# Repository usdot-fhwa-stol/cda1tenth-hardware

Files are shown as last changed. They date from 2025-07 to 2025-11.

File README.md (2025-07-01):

# cda1tenth-hardware
This repository will host any files related to the hardware development of the CDA 1Tenth system for small-scale vehicles and infrastructure in the C-ADS context.

## Contribution
Welcome to the CARMA contributing guide. Please read this guide to learn about our development process, how to propose pull requests and improvements, and how to build and test your changes to this project. [CARMA Contributing Guide](https://github.com/usdot-fhwa-stol/carma-platform/blob/develop/Contributing.md) 

## Code of Conduct 
Please read our [CARMA Code of Conduct](https://github.com/usdot-fhwa-stol/carma-platform/blob/develop/Code_of_Conduct.md) which outlines our expectations for participants within the CARMA community, as well as steps to reporting unacceptable behavior. We are committed to providing a welcoming and inspiring community for all and expect our code of conduct to be honored. Anyone who violates this code of conduct may be banned from the community.

## Attribution
The development team would like to acknowledge the people who have made direct contributions to the design and code in this repository. [CARMA Attribution](https://github.com/usdot-fhwa-stol/carma-platform/blob/develop/ATTRIBUTION.txt) 

## License
By contributing to the Federal Highway Administration (FHWA) Connected Automated Research Mobility Applications (CARMA), you agree that your contributions will be licensed under its Apache License 2.0 license. [CARMA License](https://github.com/usdot-fhwa-stol/carma-platform/blob/develop/docs/License.md) 

## Contact
Please click on the CARMA logo below to visit the Federal Highway Adminstration(FHWA) CARMA website.

CARMA Image (https://highways.dot.gov/research/research-programs/operations/CARMA)

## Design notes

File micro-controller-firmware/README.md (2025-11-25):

# Micro-controller Firmware

This firmware runs on an ESP32-S3 microcontroller to control a 1/10th scale autonomous vehicle. It provides motor control, steering, IMU sensing, and ROS 2 integration via micro-ROS.

## Hardware Requirements

### Required Components

- **ESP32-S3-DevKitC-1** development board or [CDA1Tenth PCB](docs/10th_Scale_Board.drawio.png)
- **TMC5160 Stepper Drivers** (3x):
  - One for steering motor
  - One for left drive motor
  - One for right drive motor
- **LSM6DSO IMU** sensor (6-DOF accelerometer/gyroscope)
- **Motors**: Stepper motors for drive and steering
- **Power Supply**: Appropriate voltage/current for motors and ESP32
- **USB-C Cable**: For programming and micro-ROS communication

### Pin Connections

The firmware uses the following GPIO pins on the ESP32-S3:

| Pin | Function | Description |
| --- | --- | --- |
| **SPI Bus** | | |
| IO 11 | MOSI | SPI Master Out Slave In |
| IO 12 | SCK | SPI Clock |
| IO 13 | MISO | SPI Master In Slave Out |
| **Chip Select Pins** | | |
| IO 14 | CS_IMU | Chip select for LSM6DSO IMU |
| IO 39 | CS_RIGHT | Chip select for right motor TMC5160 (TMC 5160 (0)) |
| IO 40 | CS_LEFT | Chip select for left motor TMC5160 (TMC 5160 (1)) |
| IO 41 | CS_STEER | Chip select for steering motor TMC5160 (TMC 5160 (2)) |
| **Control Pins** | | |
| IO 4 | EN_PIN | Motor enable pin |
| IO 18 | STEERING_SENSOR | Steering angle sensor (analog input) |
| IO 37 | LED_PIN | Status LED |
| **Other Pins** | | |
| IO 0 | BOOT | Boot mode selection (normally floating, can be pulled low with S2) |
| EN | RESET | Reset pin (normally pulled up, can be pulled low with S1) |
| IO 1-2 | ESTOP | Emergency stop pins (connected to TMC5160 estop) |
| IO 17 | BATTERY_VOLTAGE | Battery voltage monitoring (1:8 voltage divider) |
| IO 19-20 | USB | USB connection pins |

> **Note:** A detailed PCB diagram (`10th_Scale_Board.drawio.png`) is available in the `docs/` folder showing the complete board layout, pin connections, and component placement.

## Building and Running

0. Install Platform IO using the following installation [guide](https://docs.platformio.org/en/latest/integration/ide/vscode.html#installation)

1. Build the project:

   ```bash
   pio run
   ```

2. Use a USB cable to connect your laptop to the micro-controller board's USB-C port

3. Put the ESP32 into the manual bootloader mode ([docs by EXPRESSIF](https://docs.espressif.com/projects/esptool/en/latest/esp32/advanced-topics/boot-mode-selection.html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)).

4. Upload to your ESP32:

   ```bash
   pio run --target upload
   ```

5. Monitor serial output:

   ```bash
   pio device monitor
   ```

## micro-ROS Agent Setup

The firmware communicates with ROS 2 through a micro-ROS agent that must be running on your computer. The agent bridges the serial connection between the ESP32 and your ROS 2 network.

### Quick Start

A startup script is provided (`micro-ros-startup.sh`) that launches the agent with the correct settings:

```bash
./micro-ros-startup.sh
```

### Manual Setup

If you need to run the agent manually or on a different system:

1. **Install micro-ROS Agent** (if using Vulcanexus distribution):

   ```bash
   source /opt/vulcanexus/humble/setup.bash
   ```

2. **Identify the serial port**:

   - **Linux**: Usually `/dev/ttyACM0` or `/dev/ttyUSB0`
   - **Windows**: Usually `COM3`, `COM4`, etc. (check Device Manager)
   - **macOS**: Usually `/dev/cu.usbmodem*` or `/dev/tty.usbmodem*`

3. **Run the agent**:

   ```bash
   ros2 run micro_ros_agent micro_ros_agent serial --dev <PORT> --baudrate 921600 -v6
   ```

   Example for Linux:

   ```bash
   ros2 run micro_ros_agent micro_ros_agent serial --dev /dev/ttyACM0 --baudrate 921600 -v6
   ```

   Example for Windows (using WSL or native):

   ```bash
   ros2 run micro_ros_agent micro_ros_agent serial --dev COM3 --baudrate 921600 -v6
   ```

### Verifying Connection

Once the agent is running and the ESP32 is powered on:

- The ESP32 LED should turn **ON** (solid) when connected
- You should see connection messages in the agent terminal
- You can verify topics are available:
  ```bash
  ros2 topic list
  ```
  You should see `/car/car_state` and `/car/debug_data` topics.

## ROS 2 Topics and Messages

The `car_controller` node communicates via the following ROS 2 topics:

### Subscriptions

| Topic | Message Type | Description | Rate |
| --- | --- | --- | --- |
| `/cmd_vel_filtered` | `geometry_msgs/Twist` | Velocity commands (linear.x, angular.z) | Variable |
| `/car/config` | `car_config_msg/CarConfig` | Configuration parameters | 1 Hz (from car_odometry node) |

**`/cmd_vel_filtered` (geometry_msgs/Twist):**

- `linear.x`: Forward/backward velocity in m/s
- `angular.z`: Rotational velocity in rad/s
- **Safety**: Commands timeout after 200ms if no new command is received (car stops)

**`/car/config` (car_config_msg/CarConfig):**

- `wheelbase`: Distance between front and rear axles (meters)
- `track_width`: Distance between left and right wheels (meters)
- `wheel_radius`: Wheel radius (meters)
- `encoder_offset`: Steering encoder offset (degrees)
- `max_steering_angle`: Maximum steering angle (degrees)
- `max_rpm`: Maximum motor RPM

### Publications

| Topic | Message Type | Description | Rate  |
| --- | --- | --- | ----- |
| `/car/car_state`  | `car_state_msg/CarState` | Complete car state (IMU, motors, steering) | 20 Hz |
| `/car/debug_data` | `std_msgs/Float32MultiArray` | Debug information array | 2 Hz  |

**`/car/car_state` (car_state_msg/CarState):**

- `header`: ROS 2 header with timestamp and frame_id ("base_link")
- `accel_x/y/z`: Accelerometer data (m/s²)
- `gyro_x/y/z`: Gyroscope data (rad/s)
- `speed`: Current car speed (m/s)
- `steering_angle`: Actual steering angle (degrees)
- `right_motor_rpm`: Right motor RPM
- `left_motor_rpm`: Left motor RPM

**`/car/debug_data` (std_msgs/Float32MultiArray):**

- Array of 20 float values containing debug information (see Debug Data section below)

### Viewing Topics

To monitor the car state:

```bash
ros2 topic echo /car/car_state
```

To send velocity commands:

```bash
ros2 topic pub --once /cmd_vel_filtered geometry_msgs/msg/Twist "{linear: {x: 0.5, y: 0.0, z: 0.0}, angular: {x: 0.0, y: 0.0, z: 0.2}}"
```

## System Architecture

The firmware implements a multi-timer control system with ROS 2 integration via micro-ROS:

```mermaid
graph TB

subgraph ROS["ROS 2 System"]
    CMD[cmd_vel_filtered]
    CONFIG[car/config]
    STATE[car_state]
    DEBUG[debug_data]
end

subgraph AGENT["micro-ROS Agent"]
    BRIDGE[Serial/USB Bridge]
end

subgraph FW["ESP32-S3 Firmware"]
    NODE[car_controller Node]
    CONTROL[Control Logic]
    SENSORS[Sensing]
    MOTORCTRL[Motor Control]
end

subgraph HW["Hardware"]
    MOTORS[Drive & Steering Motors]
    IMU[IMU]
    ENC[Steering Encoder]
    LED[Status LED]
end

%% ROS2 topics to micro-ROS Agent
CMD --> BRIDGE
CONFIG --> BRIDGE

%% Agent to Firmware
BRIDGE --> NODE

%% Main data flow inside firmware
NODE --> CONTROL
NODE --> SENSORS

SENSORS --> CONTROL
CONTROL --> MOTORCTRL

%% Firmware to hardware
MOTORCTRL --> MOTORS
SENSORS --> IMU
SENSORS --> ENC
CONTROL --> LED

%% Firmware publishes back to ROS 2
CONTROL --> STATE
CONTROL --> DEBUG
STATE --> BRIDGE
DEBUG --> BRIDGE
```

### Control Loops

1. **Control Timer** (20ms / 50 Hz)

   - Processes velocity commands
   - Calculates steering angles and motor speeds
   - Updates motor control loops
   - Updates IMU sensor readings

2. **Kinematics Timer** (50ms / 20 Hz)

   - Publishes car state to `/car/car_state`
   - Includes IMU data, motor RPMs, steering angle

3. **Debug Timer** (500ms / 2 Hz)
   - Publishes debug data array to `/car/debug_data`
   - Includes system health, timing, and diagnostic information

### Data Flow

The diagram above shows the complete system architecture. Key data flows:

- **Command Flow**: `/cmd_vel_filtered` → micro-ROS Agent → ESP32 → Motor Control
- **Configuration Flow**: `/car/config` → micro-ROS Agent → ESP32 → Parameter Updates
- **State Flow**: ESP32 Sensors → Control System → `/car/car_state` → ROS 2 Network
- **Debug Flow**: ESP32 Diagnostics → Debug Timer → `/car/debug_data` → ROS 2 Network

### Connection States

The firmware manages connection state through a state machine:

- **WAITING_AGENT**: Waiting for micro-ROS agent to be available
- **AGENT_AVAILABLE**: Agent detected, creating ROS entities
- **AGENT_CONNECTED**: Connected and operating normally
- **AGENT_DISCONNECTED**: Connection lost, cleaning up

## LED Status Codes

The ESP32 board LED (IO 37) provides visual feedback about the system status:

| LED Pattern | Meaning |
| --- | --- |
| **1 flash** | Waiting for USB serial connection |
| **2 flashes** | Initial setup complete |
| **3 flashes** | Sensor initialization failed OR connection established |
| **4 flashes** | Failed to create ROS entities (retrying) |
| **5 flashes** | micro-ROS agent disconnected |
| **6 flashes** | micro-ROS transport initialized |
| **7 flashes** | Main loop started |
| **8 flashes** | Waiting for micro-ROS agent |
| **Solid ON** | Connected and operating normally |
| **Solid OFF** | Not connected or error state |
| **Continuous 2 flashes** | Fatal ROS error (system halted) |

## Configuring the Car Controller

The `car_controller` node on the ESP32 receives its configuration from the `car_odometry` node via the `/car/config` topic. To configure parameters such as `encoder_offset`, `wheel_radius`, `wheelbase`, `track_width`, `max_steering_angle`, and `max_rpm`, you need to set them in the `car_odometry` node.

For detailed instructions on how to configure the `car_odometry` node and set parameters like `encoder_offset`, please refer to the [car_odometry README](https://github.com/Michael7371/cda1tenth-bringup/blob/develop/car_odom_node/README.md).

The `car_odometry` node publishes configuration messages to `/car/config` at 1 Hz, which the `car_controller` node subscribes to and uses to update its internal parameters.

### Quick Reference

The `encoder_offset` parameter is particularly important for accurate steering control. It compensates for the initial encoder position and should be calibrated for your specific hardware setup. Other key parameters include:

- `wheel_radius`: Wheel radius in meters (default: 0.0325)
- `wheelbase`: Distance between front and rear axles in meters (default: 0.185)
- `track_width`: Distance between left and right wheels in meters (default: 0.15)
- `encoder_offset`: Steering encoder offset in degrees (default: 187.5)
- `max_steering_angle`: Maximum steering angle in degrees (default: 30.0)
- `max_rpm`: Maximum motor RPM (default: 300.0)

See the [car_odometry README](https://github.com/Michael7371/cda1tenth-bringup/blob/develop/car_odom_node/README.md) for complete parameter documentation and configuration instructions.

## Installing Custom Message Packages

The firmware uses custom ROS 2 message packages (`car_state_msg` and `car_config_msg`) that need to be built in your ROS 2 workspace.

1. Navigate to your ROS 2 workspace:

   ```bash
   # If you don't have a workspace, create one:
   mkdir -p ~/ros2_ws/src
   cd ~/ros2_ws/src
   ```

2. Copy the message packages from `extra_packages/` to your workspace:

   ```bash
   # Copy car_state_msg and car_config_msg to your workspace src directory
   ```

3. Resolve dependencies:

   ```bash
   cd ~/ros2_ws
   rosdep install --from-paths src --ignore-src -r -y
   ```

4. Build the packages:

   ```bash
   colcon build --packages-select car_state_msg car_config_msg
   ```

5. Source your workspace:

   ```bash
   source install/local_setup.bash
   ```

## Debug Data

The `/car/debug_data` topic publishes a Float32MultiArray with 20 elements containing diagnostic information:

| Index | Description | Units |
| ----- | --- | --- |
| 0 | Status flag | 1.0 = active |
| 1 | Milliseconds timestamp  | ms |
| 2 | Accelerometer X | m/s² |
| 3 | Accelerometer Y | m/s² |
| 4 | Accelerometer Z | m/s² |
| 5 | Gyroscope X | rad/s |
| 6 | Gyroscope Y | rad/s |
| 7 | Gyroscope Z | rad/s |
| 8 | Car speed | m/s |
| 9 | Steering angle | degrees |
| 10 | Connection state | 0-3 (see System Architecture) |
| 11 | Free heap memory | bytes |
| 12 | Total heap size | bytes |
| 13 | Command linear.x | m/s |
| 14 | Command angular.z | rad/s |
| 15 | Time since last command | ms |
| 16 | Time offset (ROS sync)  | ms |
| 17 | Right motor RPM | RPM |
| 18 | Left motor RPM | RPM |
| 19 | CPU frequency | MHz |

To view debug data:

```bash
ros2 topic echo /car/debug_data
```

## Troubleshooting

### Agent Not Connecting

**Symptoms**: LED stays off or flashes 8 times repeatedly, no topics visible in ROS 2

**Solutions**:

1. Verify the micro-ROS agent is running:

   ```bash
   ros2 node list
   ```

   You should see the agent node.

2. Check the serial port:

   - Verify the USB cable is connected
   - Check the port name matches in the agent command
   - Try a different USB port or cable

3. Check baud rate: Ensure agent is using 921600 baud

4. Verify ESP32 is powered and booted properly

5. Check serial monitor for error messages:

   ```bash
   pio device monitor
   ```

### Motors Not Responding

**Symptoms**: Car doesn't move when commands are sent

**Solutions**:

1. Check motor power supply is connected and adequate
2. Verify TMC5160 drivers are properly connected (SPI, CS pins)
3. Check enable pin (IO 4) is properly configured
4. Verify motor wiring (phases, power)
5. Check serial monitor for motor-related errors
6. Verify `/cmd_vel_filtered` topic is receiving messages:

   ```bash
   ros2 topic echo /cmd_vel_filtered
   ```

### IMU Not Initializing

**Symptoms**: LED flashes 3 times at startup, IMU data is zero

**Solutions**:

1. Verify IMU is connected to SPI bus
2. Check CS_IMU pin (IO 14) connection
3. Verify IMU power supply
4. Check SPI bus connections (MOSI, MISO, SCK)
5. Try re-seating the IMU module

### Serial Port Issues

**Symptoms**: Cannot upload firmware or connect to agent

**Solutions**:

1. **Windows**: Install USB-to-Serial drivers (CP210x or CH340)
2. **Linux**: Add user to dialout group:

   ```bash
   sudo usermod -a -G dialout $USER
   # Log out and back in
   ```

3. Check port permissions:

   ```bash
   ls -l /dev/ttyACM0
   ```

4. Try different USB cable (some cables are power-only)
5. Check if another program is using the port

### Build Errors

**Symptoms**: `pio run` fails

**Solutions**:

1. Update PlatformIO:

   ```bash
   pio upgrade
   ```

2. Clean and rebuild:
   ```bash
   pio run --target clean
   pio run
   ```
3. Clean micro-ROS build:
   ```bash
   pio run --target clean_microros
   pio run
   ```
4. Verify all dependencies in `platformio.ini` are accessible
5. Check internet connection (needed for first-time dependency download)

### ROS 2 Topics Not Appearing

**Symptoms**: Agent connected but topics not visible

**Solutions**:

1. Verify workspace is sourced:
   ```bash
   source ~/ros2_ws/install/local_setup.bash
   ```
2. Check topic list:
   ```bash
   ros2 topic list
   ```
3. Verify custom message packages are built and sourced
4. Check agent is using correct ROS 2 distribution (Humble)
5. Restart the agent

### Steering Not Accurate

**Symptoms**: Steering angle doesn't match commands

**Solutions**:

1. Calibrate `encoder_offset` parameter (see Configuration section)
2. Verify steering sensor (IO 18) is connected
3. Check steering motor wiring and power
4. Verify gear ratio matches hardware (55:12 default)
5. Check for mechanical binding or resistance

### Command Timeout Issues

**Symptoms**: Car stops unexpectedly after 200ms

**Solutions**:

1. Verify command publishing rate is sufficient (should be >5 Hz)
2. Check network/agent latency
3. Verify `/cmd_vel_filtered` topic is being published:
   ```bash
   ros2 topic hz /cmd_vel_filtered
   ```
4. Check for message queue issues in the agent

### Getting Help

If issues persist:

1. Check serial monitor output for detailed error messages
2. Review LED status codes to identify the failure point
3. Verify all hardware connections match the pin table
4. Check the [micro-ROS documentation](https://micro.ros.org/)
5. Review the [car_odometry README](https://github.com/Michael7371/cda1tenth-bringup/blob/develop/car_odom_node/README.md) for related issues

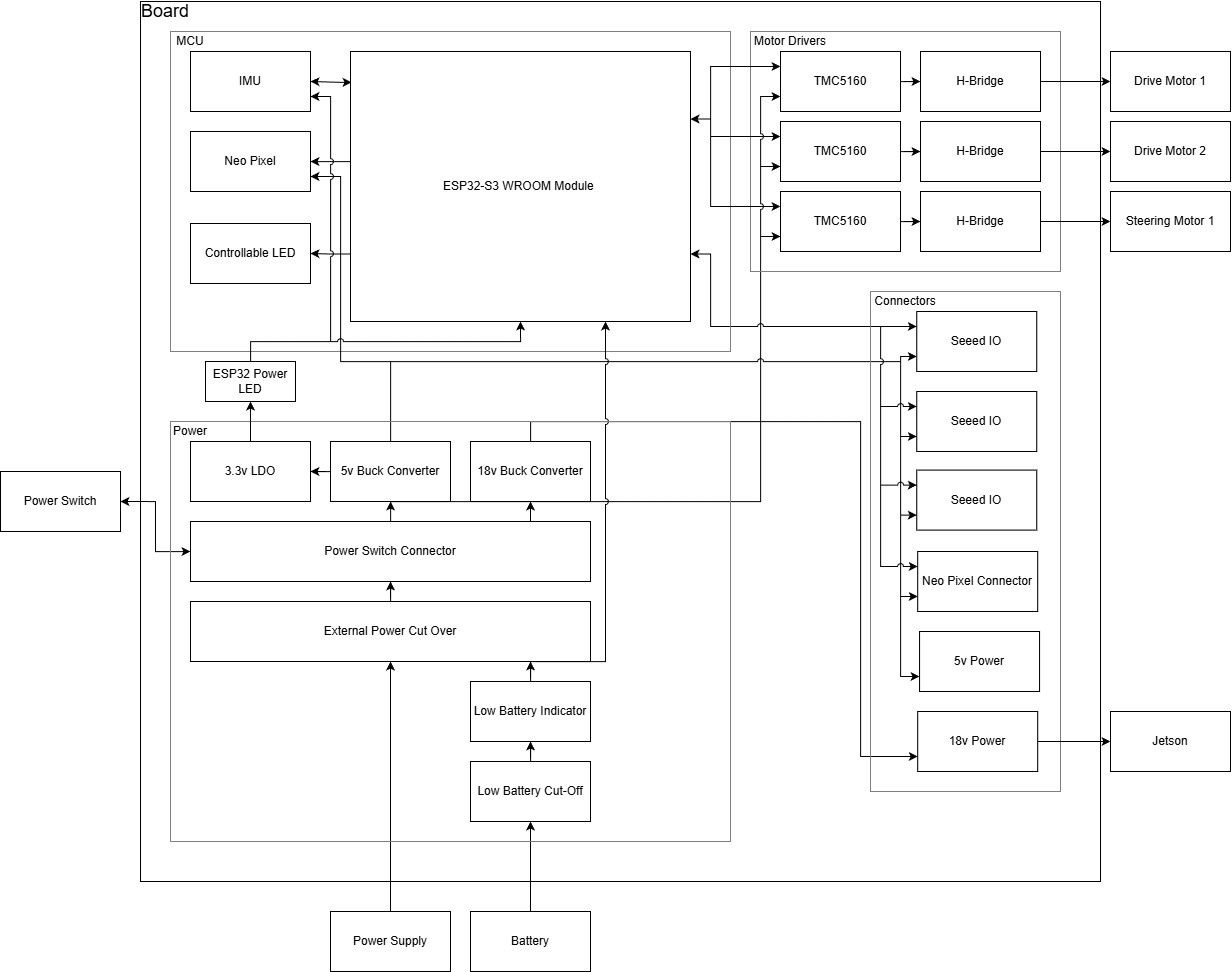
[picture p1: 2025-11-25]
micro-controller-firmware/docs/10th_Scale_Board.drawio.png

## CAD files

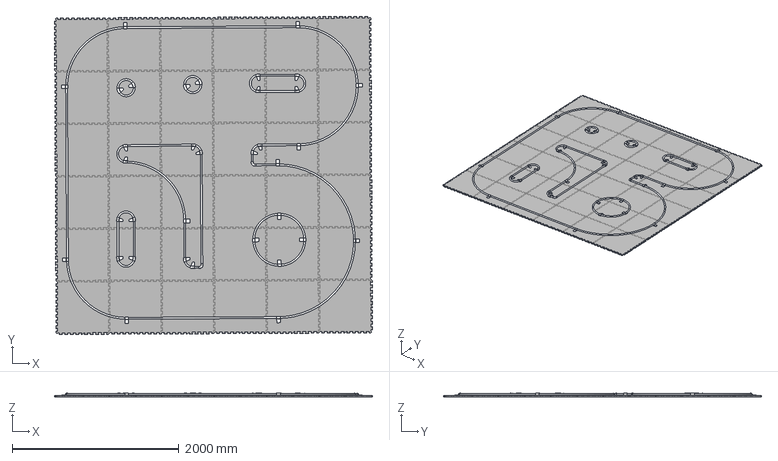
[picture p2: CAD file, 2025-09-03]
Environment-Print-Files/CDA1Tenth Field Assembly.step
3809.4 x 3809.4 x 43.8 mm

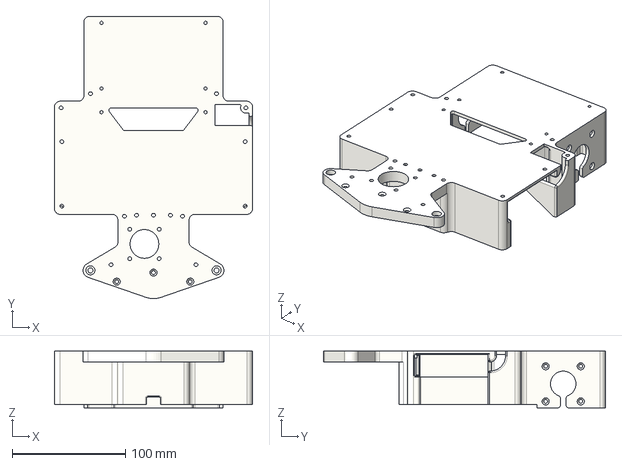
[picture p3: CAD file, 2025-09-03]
Vehicle-Print-Files/STEP/Main Body_v13.step
175.0 x 249.5 x 50.0 mm

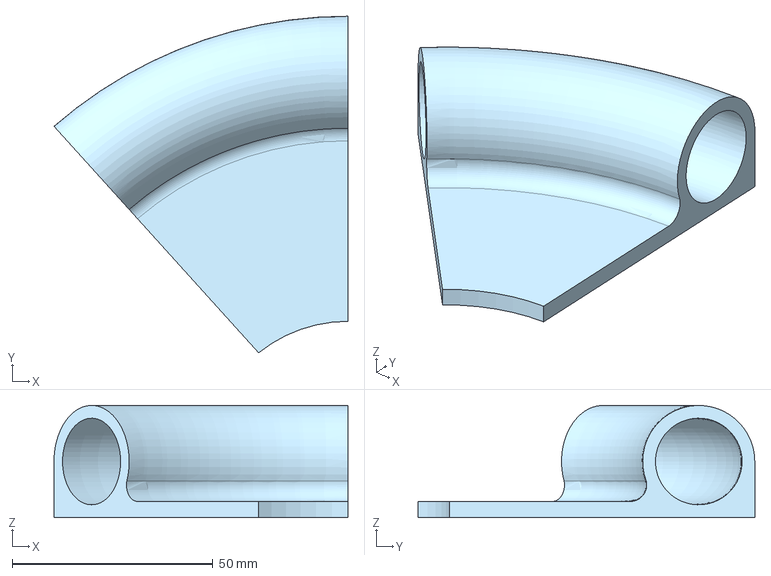
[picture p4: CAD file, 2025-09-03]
Environment-Print-Files/Connectors-no-attachment/curved.step
73.3 x 83.9 x 27.9 mm

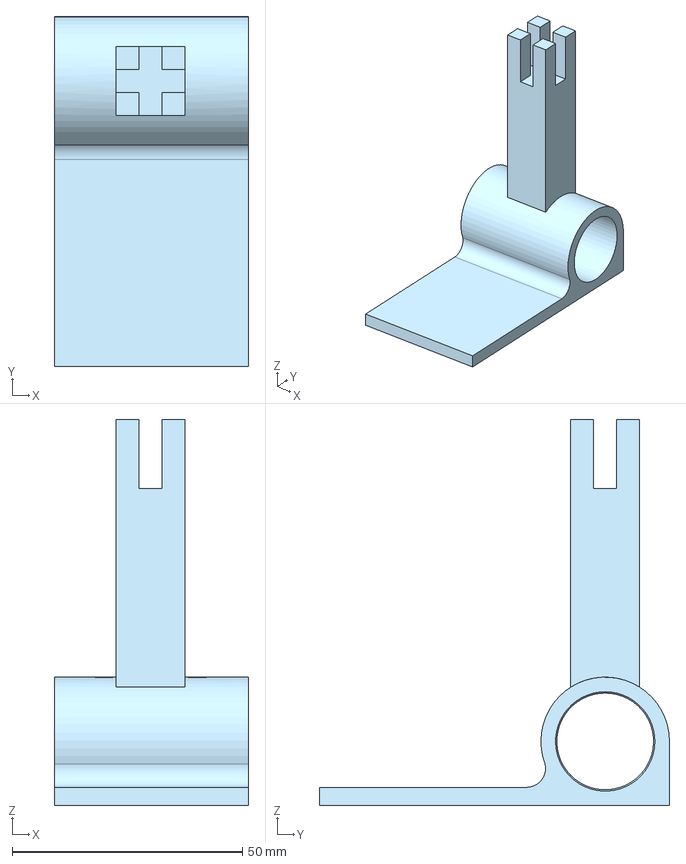
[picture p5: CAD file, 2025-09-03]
Environment-Print-Files/Connectors-with-attachments/straight_with_top.step
42.2 x 76.1 x 84.0 mm

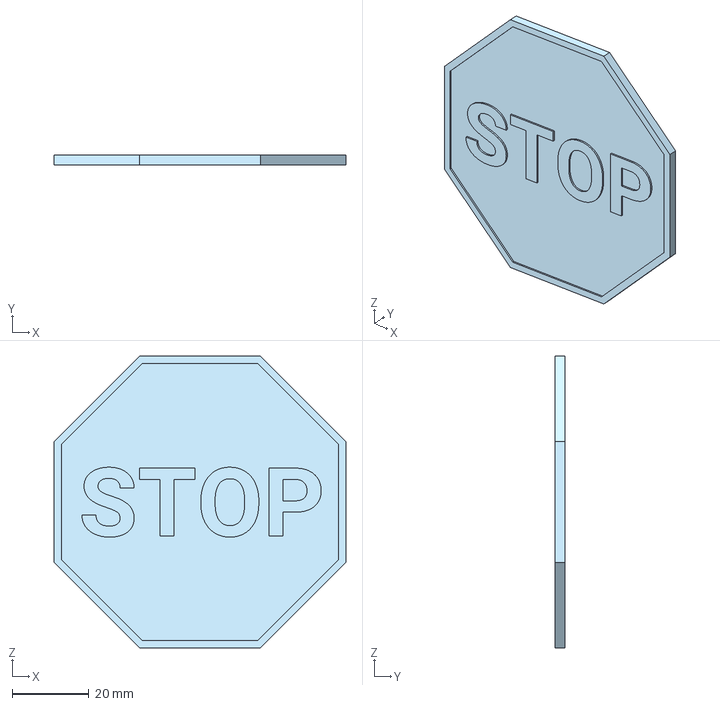
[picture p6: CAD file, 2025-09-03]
Environment-Print-Files/Signs/stop_sign.step
76.2 x 2.50 x 76.2 mm

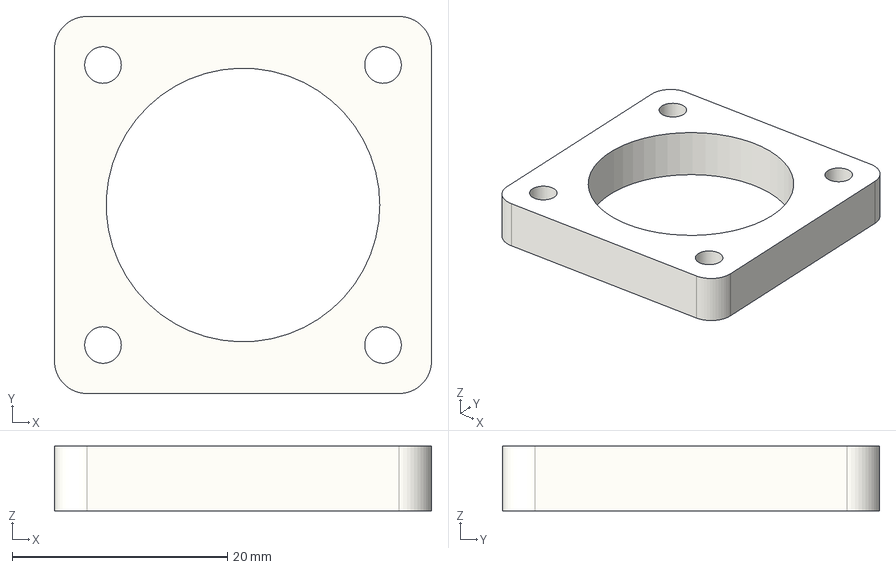
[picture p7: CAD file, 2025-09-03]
Vehicle-Print-Files/STEP/Stepper Spacer_v4.step
35.0 x 35.0 x 6.00 mm

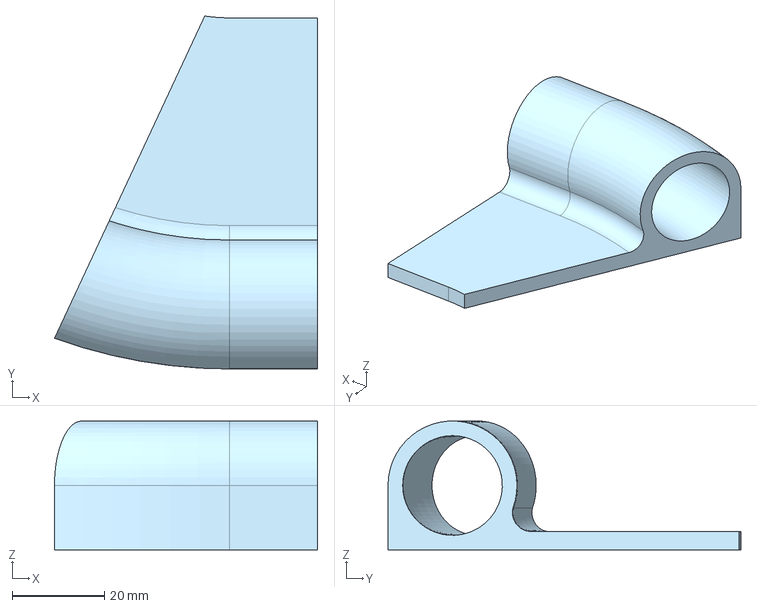
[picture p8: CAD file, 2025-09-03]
Environment-Print-Files/Connectors-no-attachment/straight_to_tight_curve_left.step
57.0 x 76.5 x 27.9 mm

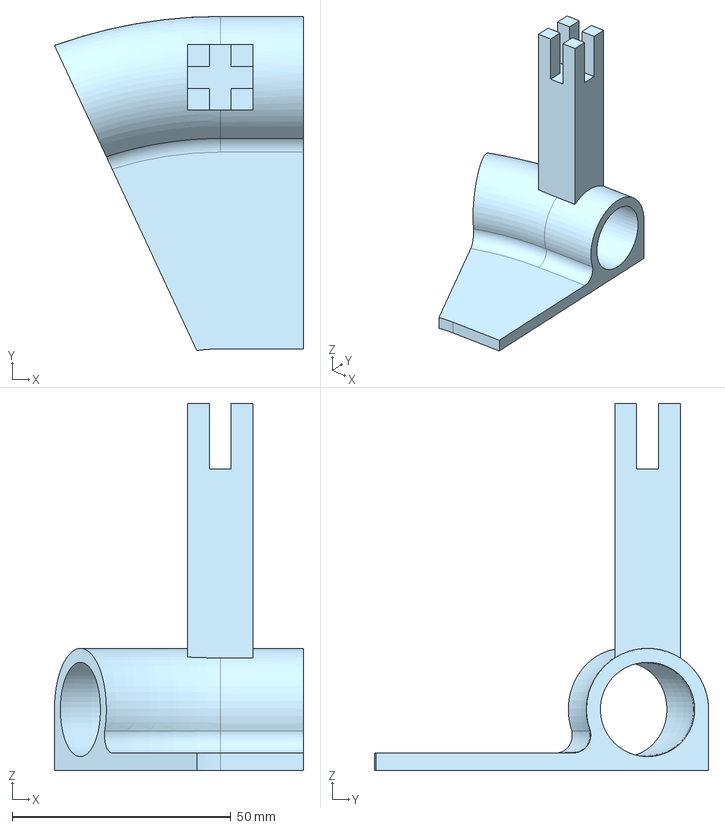
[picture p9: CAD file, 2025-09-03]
Environment-Print-Files/Connectors-with-attachments/straight_to_tight_curve_with_top_right.step
57.0 x 76.5 x 84.0 mm

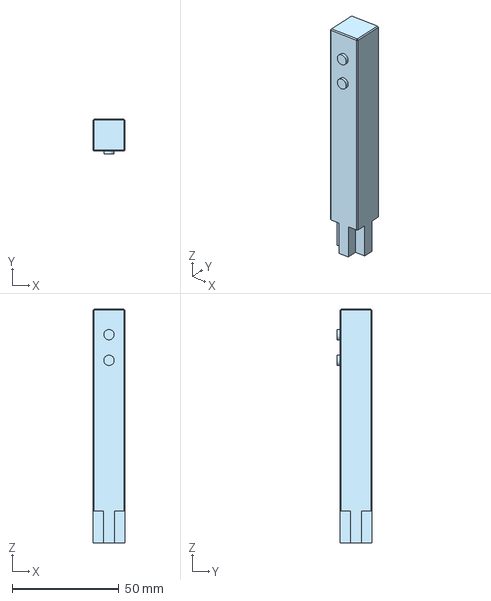
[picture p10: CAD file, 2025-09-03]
Environment-Print-Files/Signs/sign_pole.step
15.0 x 16.4 x 109.5 mm

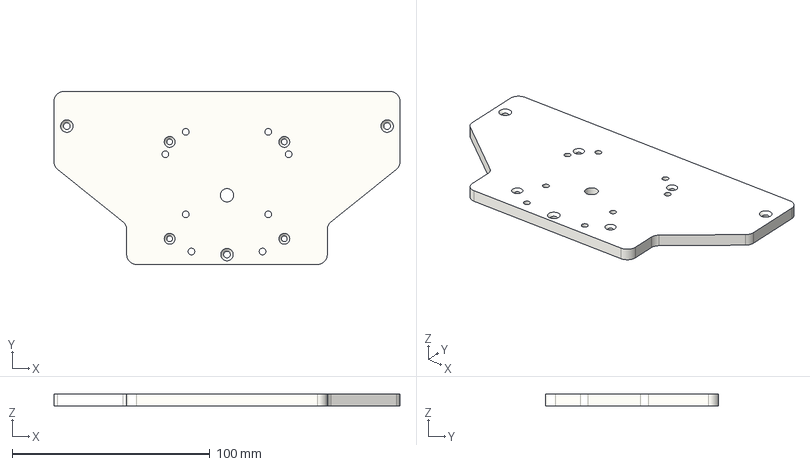
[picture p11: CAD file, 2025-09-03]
Vehicle-Print-Files/STEP/Sensor Plate RPLidar S2_v12.step
175.0 x 87.5 x 6.00 mm

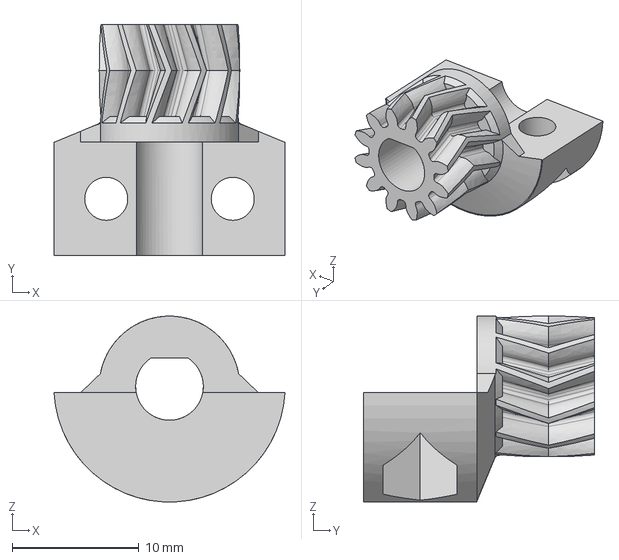
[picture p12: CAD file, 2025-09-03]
Vehicle-Print-Files/STEP/12t Pinion_v3.step
18.3 x 18.3 x 14.7 mm

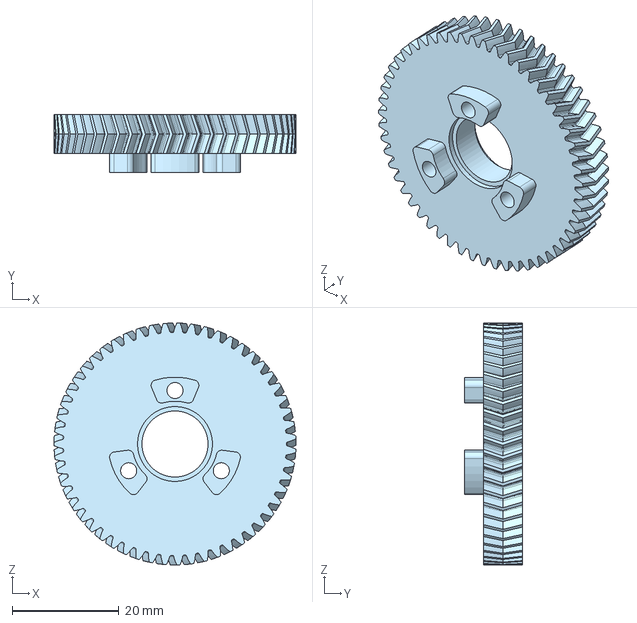
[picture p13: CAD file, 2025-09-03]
Vehicle-Print-Files/STEP/55t gear_v1.step
45.2 x 10.8 x 45.2 mm

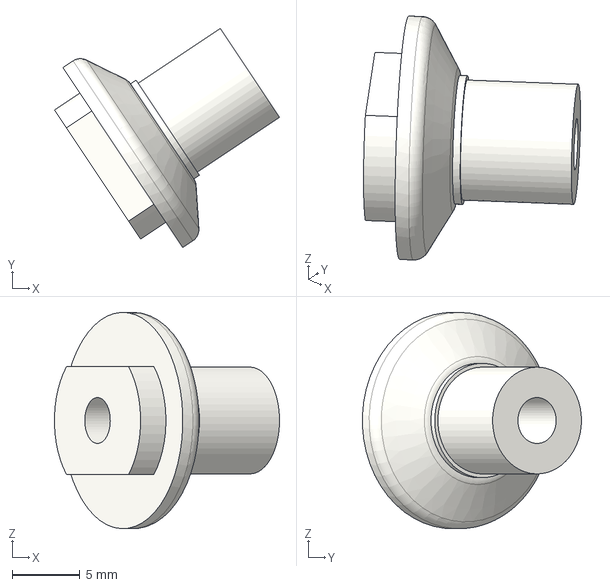
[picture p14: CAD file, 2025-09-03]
Vehicle-Print-Files/STEP/Front Wheel Stub_v5.step
16.6 x 16.2 x 16.0 mm

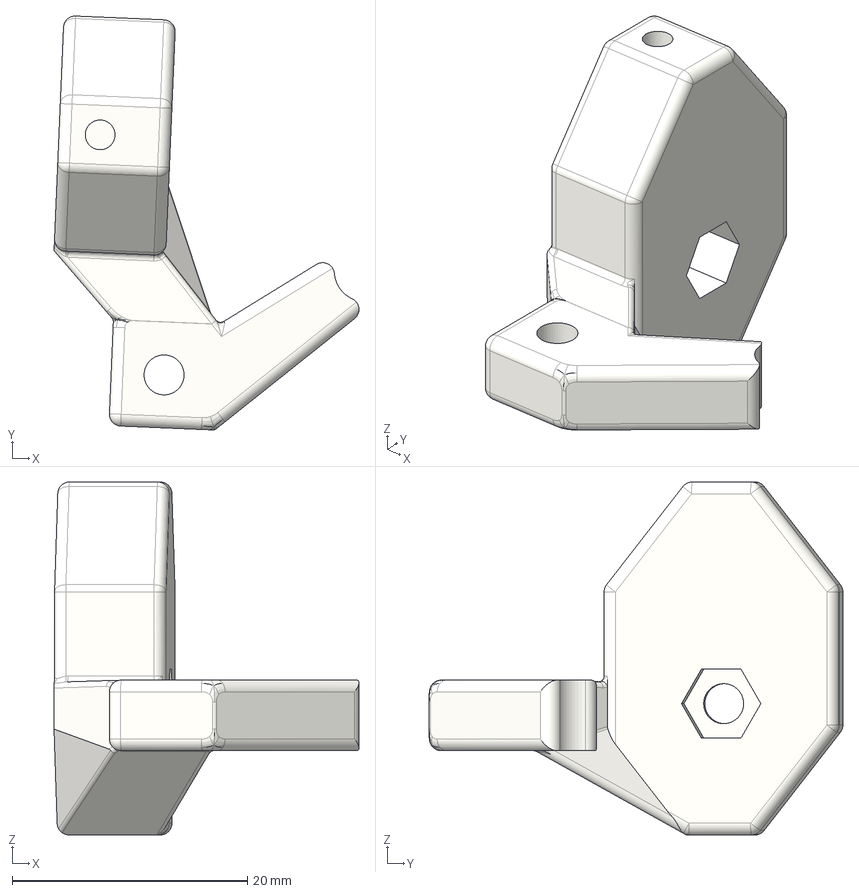
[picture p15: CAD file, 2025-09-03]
Vehicle-Print-Files/STEP/Wheel Hub Left_v3.step
25.9 x 35.2 x 30.0 mm

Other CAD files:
Environment-Print-Files/Connectors-no-attachment/straight_to_tight_curve_right.step
Environment-Print-Files/Connectors-with-attachments/straight_to_tight_curve_with_top_left.step
Vehicle-Print-Files/STEP/Steering Dead Axle_v2.step
Vehicle-Print-Files/STEP/Battery Cage_v12.step
Vehicle-Print-Files/STEP/Bottom Plate_v12.step
Vehicle-Print-Files/STEP/Camera Mount OakD Lite v5.step
Vehicle-Print-Files/STEP/Camera Mount ZEDM v3.step
Vehicle-Print-Files/STEP/Front Bumpers_v13.step
Vehicle-Print-Files/STEP/Front Left Shroud_v7.step
Vehicle-Print-Files/STEP/Front Right Shroud_v6.step
Vehicle-Print-Files/STEP/Front Wheel Washer_v5.step
Vehicle-Print-Files/STEP/Front Wheel_v5.step
Vehicle-Print-Files/STEP/Lidar clip v4.step
Vehicle-Print-Files/STEP/Motor connector 2_v5.step
Vehicle-Print-Files/STEP/Motor connector_v4.step
Vehicle-Print-Files/STEP/Pinion Clamp_v3.step
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

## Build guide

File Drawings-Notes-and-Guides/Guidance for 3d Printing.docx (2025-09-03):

### How to Print PA6-CF (Nylon 6 Carbon Fiber) Filament

- Printer Requirements:
  - Use a hardened steel or ruby-tipped nozzle to withstand carbon fiber abrasiveness.
  - An enclosed printer is recommended to prevent warping.
  - Use a direct drive extruder for better control, though high-quality Bowden setups can also work.
- Recommended Print Settings:
  - Nozzle Temperature: 260–290°C (Check manufacturer specs)
  - Bed Temperature: 70–110°C
  - Layer Height: 0.4 mm or greater (due to fiber size)
- Print Surface & Adhesion:
  - Use PEI.
  - Apply a glue stick or a PA-specific adhesive to prevent sticking too hard or warping.
- Drying the Filament:
  - Critical step – Nylon is extremely hygroscopic.
  - Dry filament at 80-90°C for 12 hours before printing.
  - Check for <20% relative humidity before printing.
  - Store in a dry box or vacuum-sealed bag with desiccant.
- Speed & Retraction:
  - Print Speed: 60 mm/s (slower for better quality)
  - Retraction: 1–2 mm @ 20–40 mm/s (tune for your setup to avoid stringing)
- Notes
  - The body shrinks enough to warrant printing at 1.01-1.02 scale.
  - For a looser battery cage fit, scale the print 0.98 - 0.99.

### How to Print PPA-CF (Carbon Fiber Reinforced Polythiazide) Filament

- Printer Requirements:
  - All-metal hotend rated for 320 °C or higher.
  - Hardened steel nozzle required (carbon fiber is abrasive).
  - Nozzle size: 0.4 mm+ (0.6 mm preferred to reduce clogging).
  - Heated enclosure recommended to prevent warping.
- Recommended Print Settings:
  - Nozzle Temperature: 280–320 °C (check your specific brand).
  - Bed Temperature: 80–120 °C (with adhesive aid).
  - Layer Height: 0.1–0.25 mm (0.2 mm typical).
  - Cooling Fan: Off or very low (0–30%).
- Print Surface & Adhesion:
  - Works well on PEI or Garolite with glue stick, Magigoo PA, or PVA glue.
  - Use a brim or raft for better first-layer grip.
  - Keep bed clean and pre-heated before printing.
- Drying the Filament:
- PPA-CF is very hygroscopic; print only when dry.
- Dry at 100–130 °C for 8–12 h (or 70 °C for 18–24 h in a filament dryer).
- Store in a dry box or airtight container with desiccant.
- Aim for <15% relative humidity.
- Speed & Retraction:
- Print Speed: 30–80 mm/s (slower for fine detail).
- Retraction: 0.5–1.5 mm @ 25–40 mm/s.
- Keep retractions minimal to avoid clogging.

Optional Post-Processing:

- Anneal printed parts at 80–100 °C for 4–12 h to improve strength and heat resistance.

### How to Print TPU (Thermoplastic Polyurethane) Filament

- Printer Requirements:
  - Direct drive extruder is highly recommended – TPU is flexible and can jam in Bowden tubes. 95A should be fine.
  - Use a printer with a fully constrained filament path to prevent buckling.
  - Works well on open-frame printers – no enclosure required.
- Recommended Print Settings:
  - Nozzle Temperature: 210–240°C (check your specific TPU brand)
  - Bed Temperature: 30–60°C (optional; helps first-layer adhesion)
  - Layer Height: 0.1–0.3 mm (0.2 mm is typical)
- Print Surface & Adhesion:
  - Sticks well to PEI.
  - Use a brim or skirt to help with initial adhesion and oozing control.
- Drying the Filament:
  - TPU is hygroscopic; it absorbs moisture easily.
  - Dry at 40–50°C for 12 hours before printing.
  - Check for <20% relative humidity before printing.
  - Store in a dry box or airtight container with desiccant.
- Speed & Retraction:
  - Print Speed: 15–60 mm/s (go slow to avoid issues)
  - Retraction: Minimal (0.5–2 mm @ 10–25 mm/s); too much can cause clogs or jams
  - Enable avoid crossing walls.
  - Disable coasting, combing, and z-hop for more consistent extrusion

### How to Remove Supports from 3D Prints

- Let the Print Cool First:
  - Allow the print to cool fully before handling—supports are easier to break off cleanly when the material is rigid.
- Start with Your Hands:
  - Gently break away large support structures by hand.
  - Flex the part slightly (if it's not brittle) to loosen supports from internal cavities.
  - Be sure to support small features when removing supports.
- Use the Right Tools:
  - Flush cutters or diagonal pliers for precise nips
  - Deburring tool or X-Acto knife for edge cleanup
  - Needle-nose pliers for tight or internal areas
  - Tweezers for stringy supports in fine details
- Use Support Interface Layers (Slicer Tip):
  - When slicing, enable support interface layers (denser contact layers) for easier, cleaner breakaway.
  - Consider "air gap" settings for easier removal—typically 0.2 mm for PLA, more for PETG or TPU.
- Print Orientation Matters:
  - Orient parts to minimize supports or make them easier to remove (e.g., flat surfaces facing down).
- Stay Safe:
  - Wear gloves and eye protection when using sharp tools.
  - Cut away from your body—many support injuries come from rushed removal.

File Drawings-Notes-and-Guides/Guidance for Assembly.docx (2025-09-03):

### How to Wire the Stepper Motors and an Encoder

- Wire Lengths:
- Switch: >6inches
- Steering Encoder: >7 inches
- Steering Motor; >4 inches
- Left Motor: > 5 inches
- Right Motor: >5 inches
- Wire Each Stepper Motor:
- Use stepper motor datasheets or a multimeter to identify coil pairs. Connect each motor’s A+ A– and B+ B– wires to the correct driver terminals. Keep wire lengths manageable and avoid crossing wires when possible.
- Connect the Encoders:
- Use the 3-pin encoder for steering and the 5-pin encoders coming out of the stepper for the drive steppers.
- When soldering the steering encoder there are 2 ways to make the encoder work correctly.
1. Solder a wire between VCC and GP0.

OR

2. Remove resistor 4.

- Secure Your Wiring:
- Make sure the steering encoder is attached to the bottom cover and routed through the vehicle before attaching the bottom cover. Label both ends of each wire for easy debugging later.
- Stay Safe:
- Disconnect power before making any changes.
- Avoid touching stepper drivers when powered—they get hot quickly.
- Keep loose wires away from fan blades or moving parts.

### Reminders for Assembling the Car

- Check All Parts First:
  - Lay out every printed piece and compare against your assembly plan or parts list.
  - Verify that parts are cleanly printed, supports are removed, and undamaged before starting.
- Check tolerances:
  - Lightly sand mating surfaces if parts are too tight or warped.
- Use Adhesives:
  - Superglue (CA glue) for plastic interfaces.
  - Loctite 425 for metal-to-metal interfaces.
  - Apply sparingly — a little goes a long way and avoids mess.
- Check Alignment and Motion:
  - Spin wheels to ensure smooth rotation and even clearance.
  - Test steering movement before locking everything in place.
  - Steering should tighten until the shoulder bolt almost peeks out from the nylon insert in the Nylock nut.
- Finish and Detail (Optional):
  - Sand seams, then prime and paint if desired.
  - Apply decals or stickers after clear-coating for best results.
- Stay Safe:
  - Wear eye protection and gloves when cutting, sanding, or using adhesives.
  - Work in a well-ventilated area when using glue or paint fumes.

### 3DP Parts List

3D Prints, Recommended Materials, and Quantity
Parts | Filament | Qty
Main Body | Bambu PA6-CF, Markforged Onyx, 3DXTech Obsidian, Polymaker HT PLA, Bambu PPA-CF, Siraya Tech PPA-CF | 1
Bottom Cover | Bambu PA6-CF, Markforged Onyx, 3DXTech Obsidian, Polymaker HT PLA, Bambu PPA-CF, Siraya Tech PPA-CF | 1
Front Bumper | Bambu 95A TPU, Markforged TPU | 1
Rear Bumper | Bambu 95A TPU, Markforged TPU | 1
Sensor Plate | Bambu PETG-CF, Bambu PA6-CF, Markforged Onyx, 3DXTech Obsidian, Polymaker HT PLA, Bambu PPA-CF, Siraya Tech PPA-CF | 1
Camera Mount | Bambu PETG-CF, Bambu PA6-CF, Markforged Onyx, 3DXTech Obsidian, Polymaker HT PLA, Bambu PPA-CF, Siraya Tech PPA-CF | 1
Wheel Hub | Bambu PETG-CF, Markforged Onyx, 3DXTech Obsidian, Polymaker HT PLA | 2
Wheel Hub Stub | Bambu PA6-CF, Markforged Onyx, 3DXTech Obsidian, Polymaker HT PLA | 2
Wheel Hub Washer | Bambu PETG-CF, Bambu PA6-CF, Markforged Onyx, 3DXTech Obsidian, Polymaker HT PLA, Bambu PPA-CF, Siraya Tech PPA-CF | 3
Steering Washer | Bambu PETG-CF, Bambu PA6-CF, Markforged Onyx, 3DXTech Obsidian, Polymaker HT PLA, Bambu PPA-CF, Siraya Tech PPA-CF | 1
Steering Rod | Bambu PA6-CF, Markforged Onyx, 3DXTech Obsidian, Polymaker HT PLA, Bambu PPA-CF, Siraya Tech PPA-CF | 1
Motor Connector 1 | Bambu PA6-CF, Markforged Onyx, 3DXTech Obsidian, Polymaker HT PLA, Bambu PPA-CF, Siraya Tech PPA-CF | 1
Motor Connector 2 | Bambu PA6-CF, Markforged Onyx, 3DXTech Obsidian, Polymaker HT PLA, Bambu PPA-CF, Siraya Tech PPA-CF | 1
12t Pinion | Bambu PA6-CF, Markforged Onyx, 3DXTech Obsidian, Polymaker HT PLA, Bambu PPA-CF, Siraya Tech PPA-CF | 1
55t Gear | Bambu PA6-CF, Markforged Onyx, 3DXTech Obsidian, Polymaker HT PLA, Bambu PPA-CF, Siraya Tech PPA-CF | 1
Pinion Clamp | Bambu PA6-CF, Markforged Onyx, 3DXTech Obsidian, Polymaker HT PLA, Bambu PPA-CF, Siraya Tech PPA-CF | 1
Steering dead axle | Bambu PA6-CF, Markforged Onyx, 3DXTech Obsidian, Polymaker HT PLA, Bambu PPA-CF, Siraya Tech PPA-CF | 1
Stepper Spacer | Bambu PA6-CF, Markforged Onyx, 3DXTech Obsidian, Polymaker HT PLA, Bambu PPA-CF, Siraya Tech PPA-CF | 1
Front Wheel Rim | Bambu PETG-CF, Markforged Onyx, 3DXTech Obsidian, Polymaker HT PLA, Bambu PPA-CF, Siraya Tech PPA-CF | 2
Rear Wheel | Bambu PETG-CF, Markforged Onyx, 3DXTech Obsidian, Polymaker HT PLA, Bambu PPA-CF, Siraya Tech PPA-CF | 2
Tire | Bambu 95A TPU, Markforged TPU | 4
Front Right Shroud | Bambu PETG, Polymaker HT PLA, Bambu PPA-CF, Siraya Tech PPA-CF | 1
Front Left Shroud | Bambu PETG, Polymaker HT PLA, Bambu PPA-CF, Siraya Tech PPA-CF | 1
Rear Right Shroud | Bambu PETG, Polymaker HT PLA, Bambu PPA-CF, Siraya Tech PPA-CF | 1
Rear Left Shroud | Bambu PETG, Polymaker HT PLA, Bambu PPA-CF, Siraya Tech PPA-CF | 1
Tire | Bambu 95A TPU, Markforged TPU | 4

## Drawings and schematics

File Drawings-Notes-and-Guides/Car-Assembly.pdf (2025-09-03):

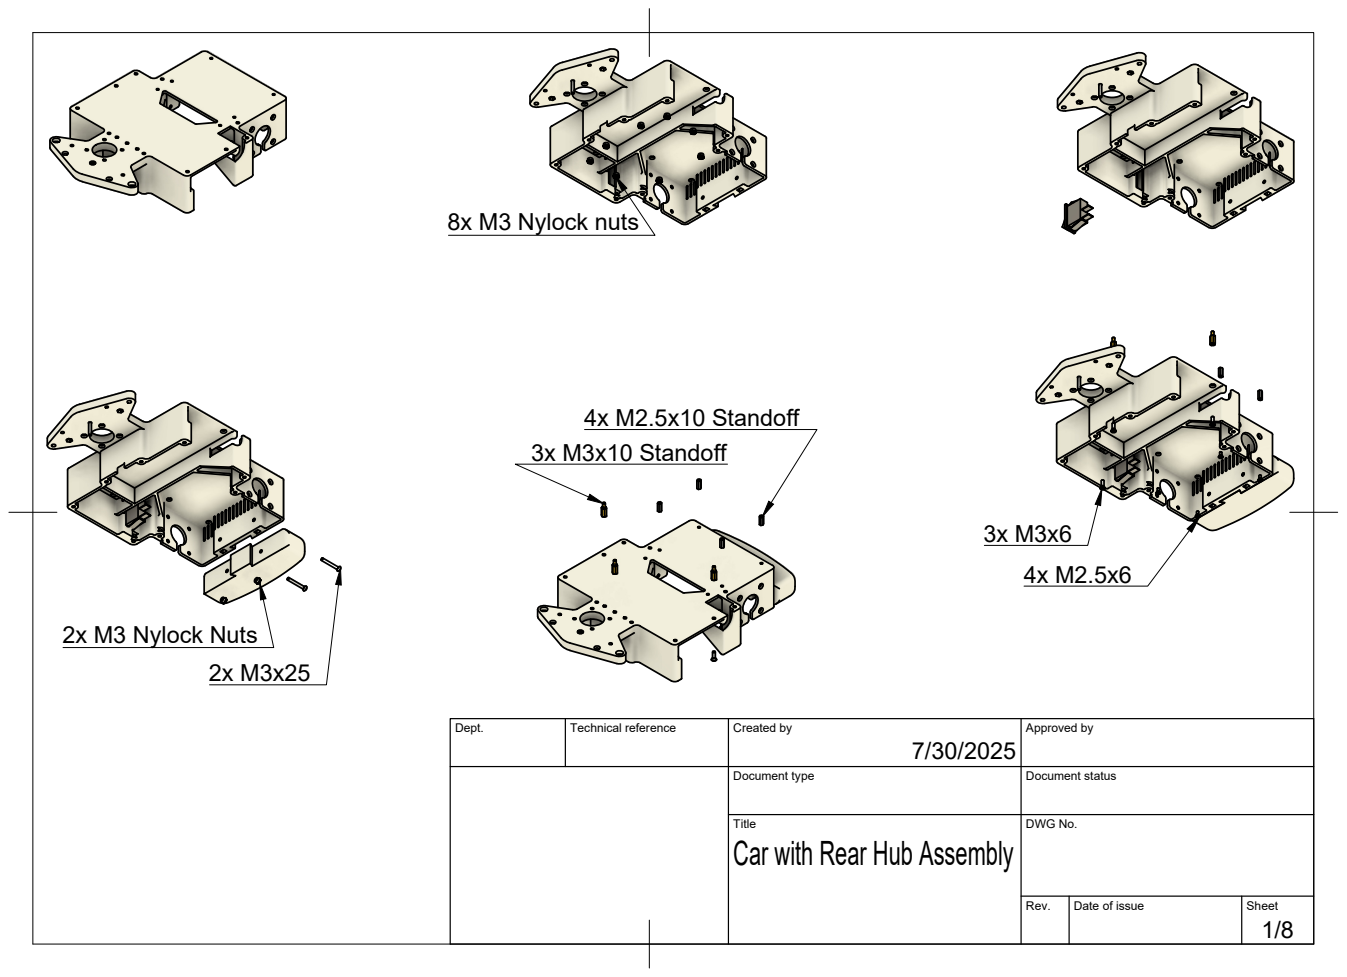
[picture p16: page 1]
8x M3 Nylock nuts; 2x M3 Nylock Nuts; 3x M3x10 Standoff; 4x M2.5x10 Standoff

Dept. | Technical reference | Created by 7/30/2025 | Approved by

Document type | Document status

Title Car with Rear Hub Assembly | DWG No.

Rev. | Date of issue | Sheet

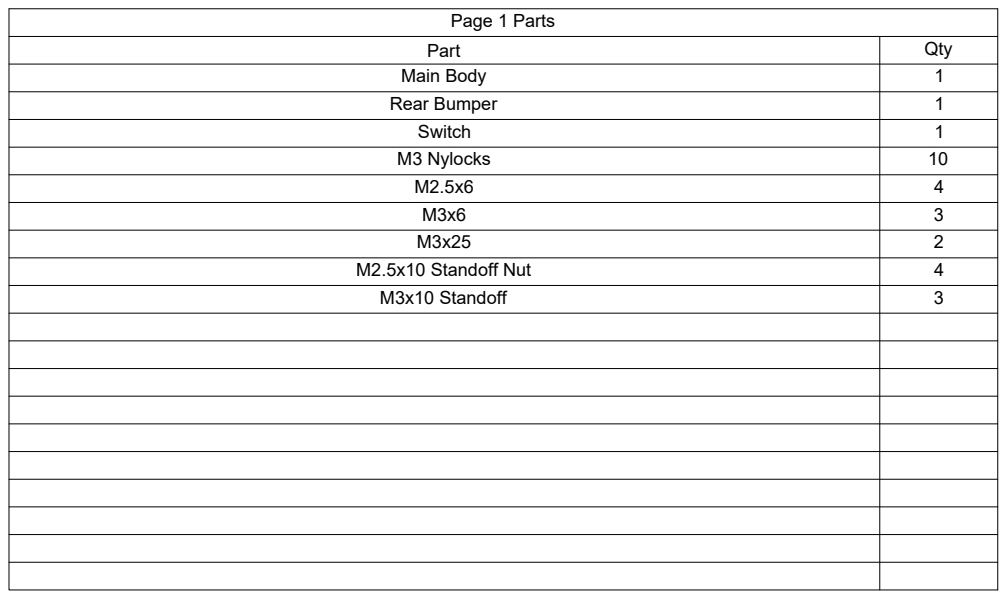
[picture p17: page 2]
Page 1 Parts

Part | Qty
Main Body | 1
Rear Bumper | 1
Switch | 1
M3 Nylocks | 10
M2.5x6 | 4
M3x6 | 3
M3x25 | 2

M2.5x10 Standoff Nut | 4
M3x10 Standoff | 3

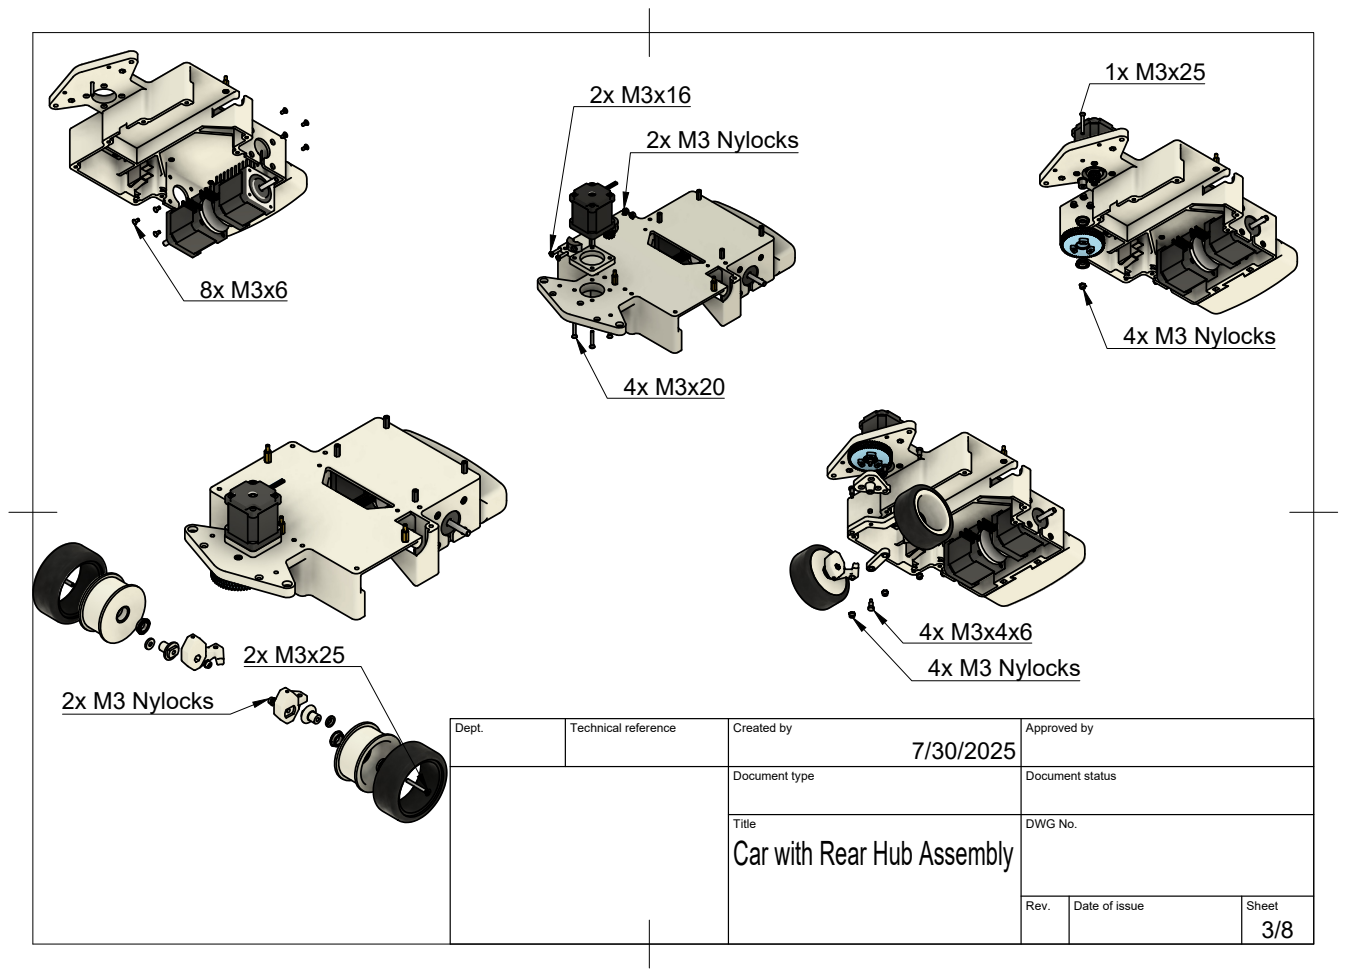
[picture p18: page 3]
Dept.; Technical reference; Created by; Approved by; Document type; Document status; Title; DWG No.; Rev.; Date of issue; Sheet; 2x M3 Nylocks; 4x M3 Nylocks

Car with Rear Hub Assembly

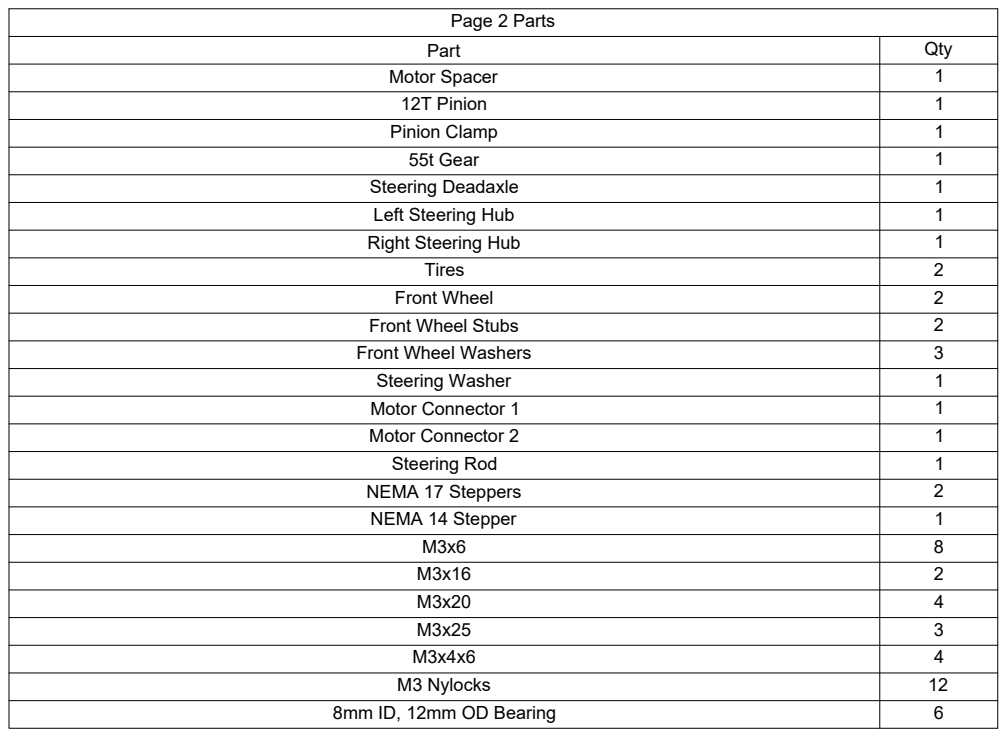
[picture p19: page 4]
Page 2 Parts; Motor Spacer; 12T Pinion; Pinion Clamp; 55t Gear; Steering Deadaxle; Left Steering Hub; Right Steering Hub; Front Wheel; Front Wheel Stubs; Front Wheel Washers; Steering Washer; Motor Connector 1; Motor Connector 2; Steering Rod; NEMA 17 Steppers; NEMA 14 Stepper; M3 Nylocks; 8mm ID, 12mm OD Bearing

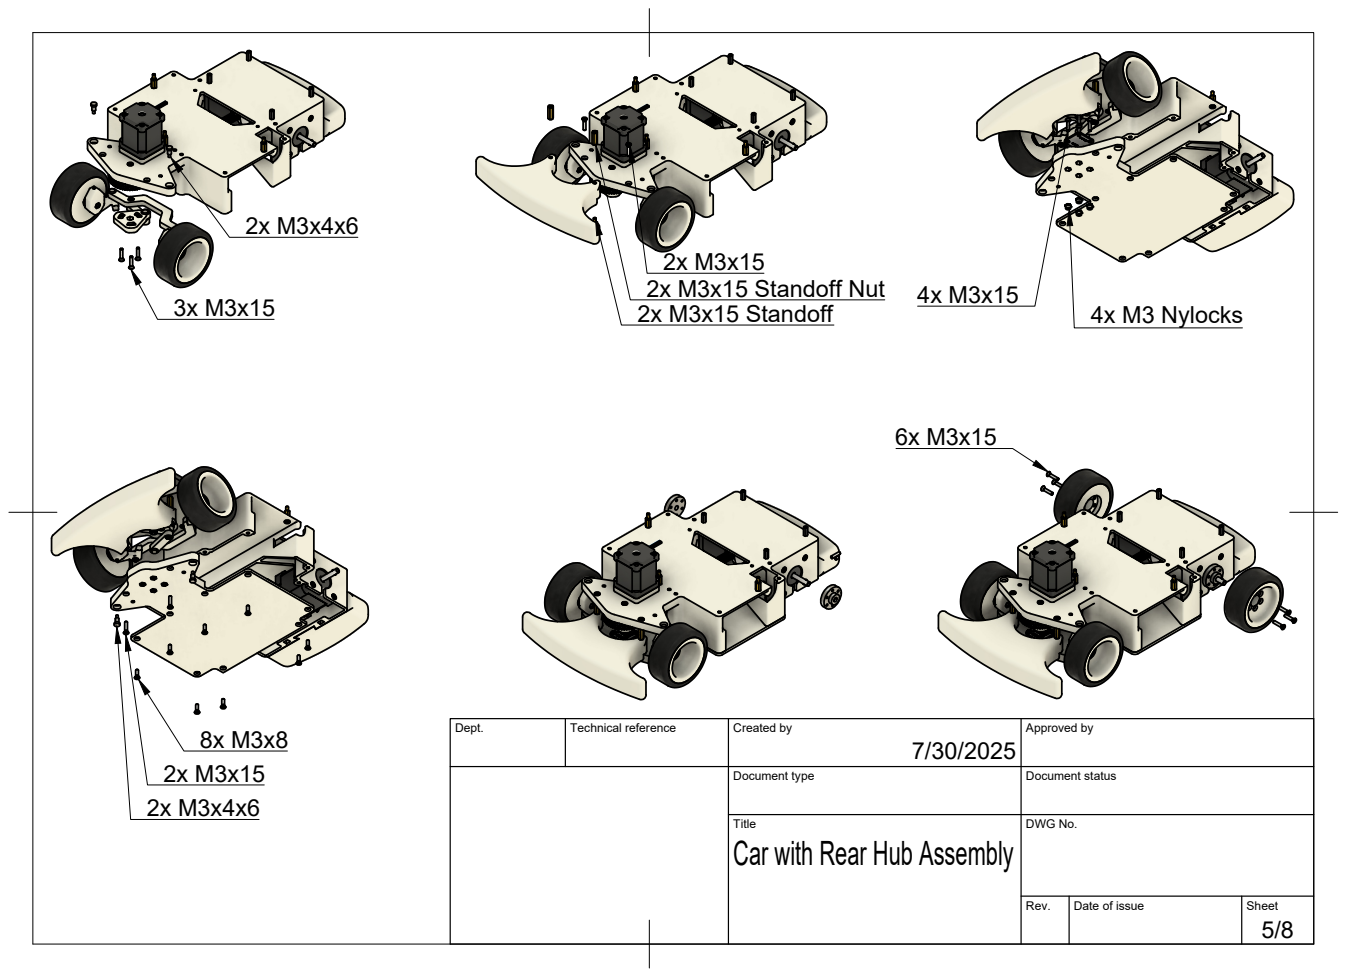
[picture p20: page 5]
Dept.; Technical reference; Created by; Approved by; Document type; Document status; Title; DWG No.; Rev.; Date of issue; Sheet; 2x M3x15 Standoff Nut 2x M3x15 Standoff; 4x M3 Nylocks

Car with Rear Hub Assembly

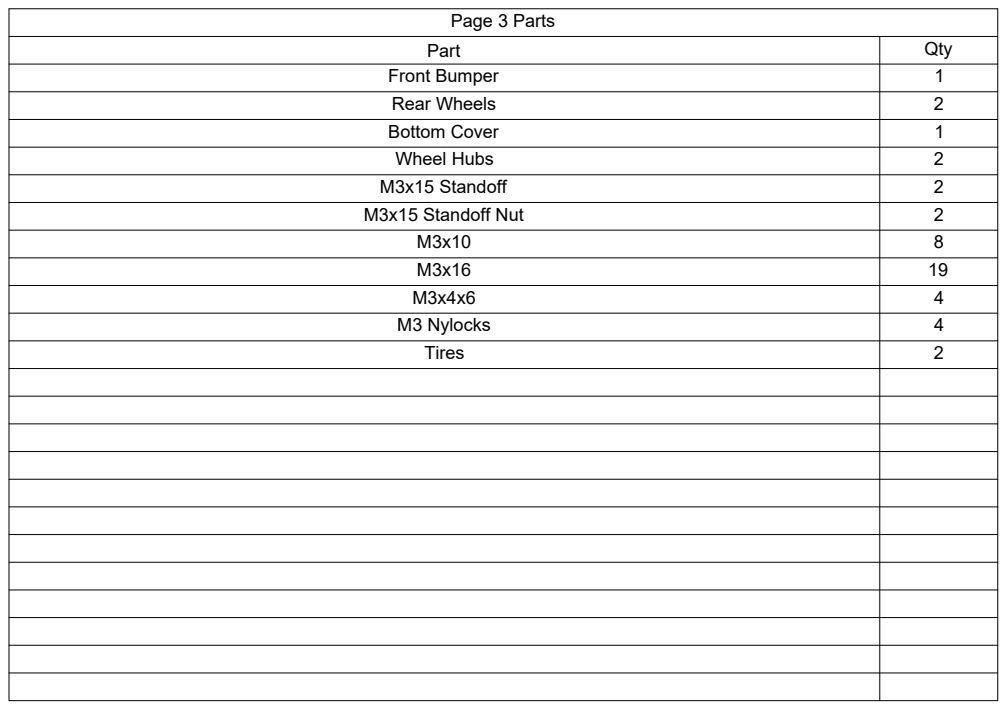
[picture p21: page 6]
Page 3 Parts

Part | Qty
Front Bumper | 1
Rear Wheels | 2
Bottom Cover | 1
Wheel Hubs | 2
M3x15 Standoff | 2
M3x15 Standoff Nut | 2

M3x10 | 8
M3x16 | 19
M3x4x6 | 4
M3 Nylocks | 4
Tires | 2

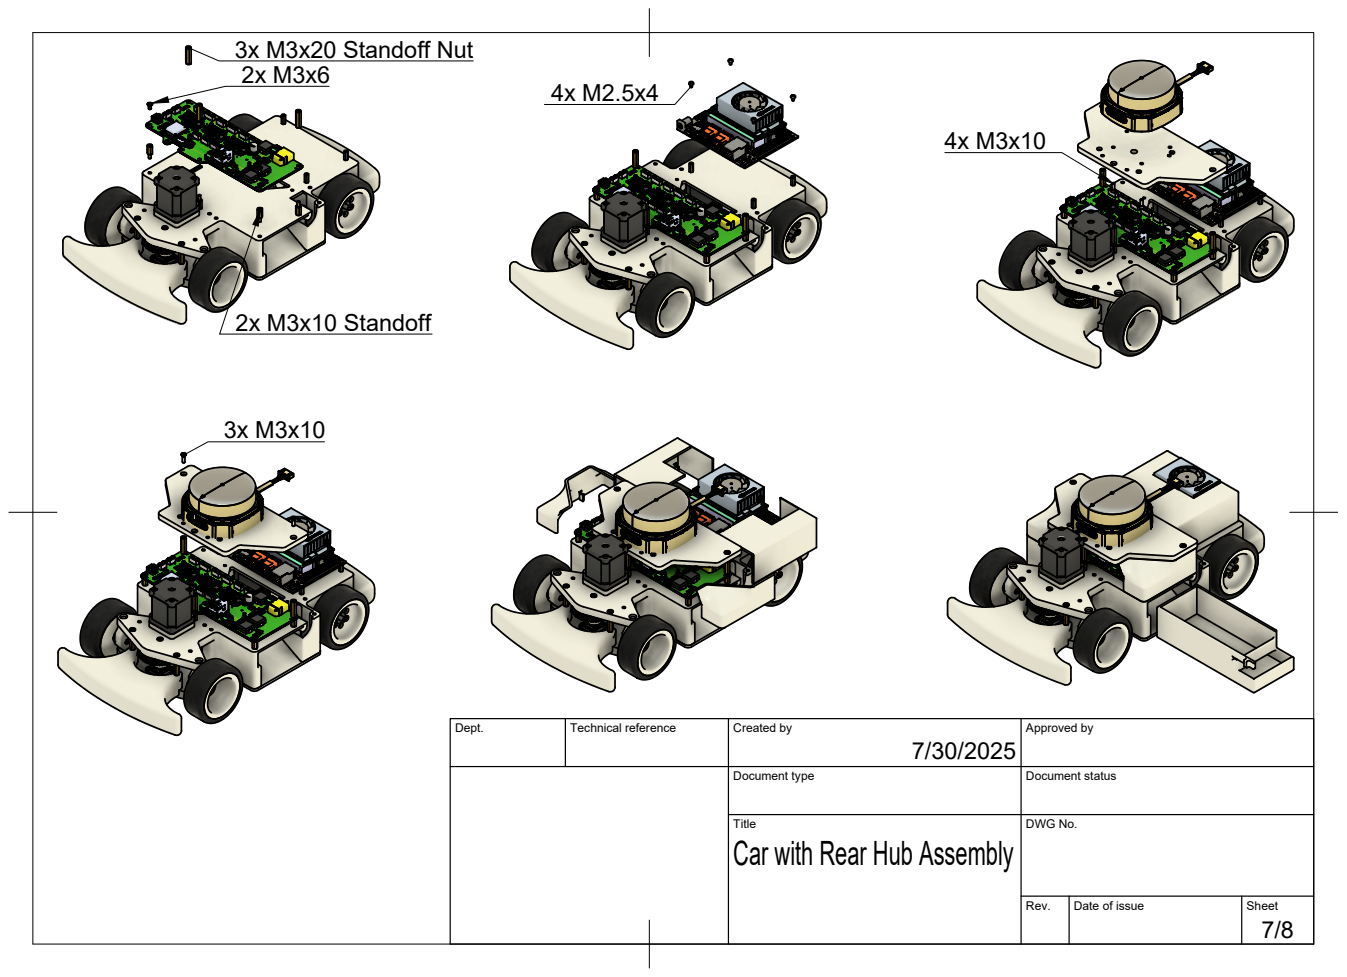
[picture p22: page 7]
Dept.; Technical reference; Created by; Approved by; Document type; Document status; Title; DWG No.; Rev.; Date of issue; Sheet; 3x M3x20 Standoff Nut 2x M3x6; 2x M3x10 Standoff

Car with Rear Hub Assembly

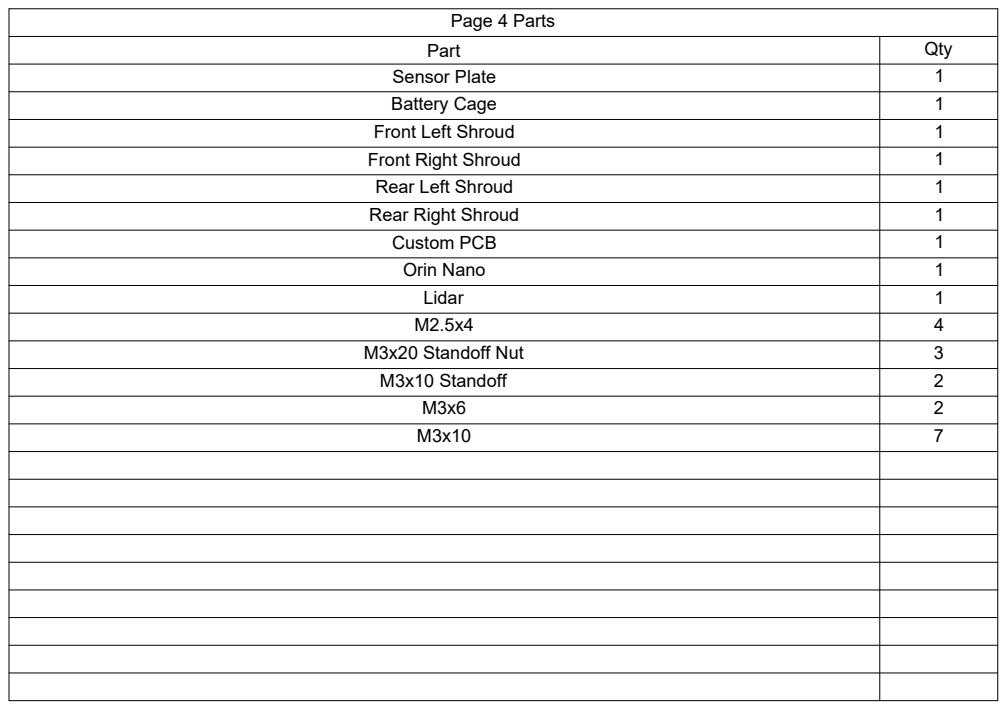
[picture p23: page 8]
Page 4 Parts

Part | Qty
Sensor Plate | 1
Battery Cage | 1
Front Left Shroud | 1
Front Right Shroud | 1
Rear Left Shroud | 1
Rear Right Shroud | 1
Custom PCB | 1
Orin Nano | 1
Lidar | 1
M2.5x4 | 4
M3x20 Standoff Nut | 3
M3x10 Standoff | 2
M3x6 | 2
M3x10 | 7

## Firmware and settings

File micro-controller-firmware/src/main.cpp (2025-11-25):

#include <Arduino.h>
#include "USB.h"
#include "USBCDC.h"
#include <micro_ros_platformio.h>
#include <stdio.h>

#include <rcl/rcl.h>
#include <rcl/error_handling.h>
#include <rclc/rclc.h>
#include <rclc/executor.h>

#include <sensor_msgs/msg/imu.h>
#include <geometry_msgs/msg/twist.h>
#include <std_msgs/msg/float32_multi_array.h>
#include <string.h>
#include <geometry_msgs/msg/vector3.h>
#include <std_msgs/msg/header.h>
#include <car_state_msg/msg/car_state.h>
#include <car_config_msg/msg/car_config.h>

#include "car.h"
#include "sensor_manager.h"
#include "debug.h"

#ifndef RCCHECK
#define RCCHECK(fn)              \
  {                              \
    rcl_ret_t temp_rc = fn;      \
    if ((temp_rc != RCL_RET_OK)) \
    {                            \
      rclErrorLoop();            \
    }                            \
  }
#endif
#define RCSOFTCHECK(fn)          \
  {                              \
    rcl_ret_t temp_rc = fn;      \
    if ((temp_rc != RCL_RET_OK)) \
    {                            \
    }                            \
  }
#define EXECUTE_EVERY_N_MS(MS, X)      \
  do                                   \
  {                                    \
    static volatile int64_t init = -1; \
    if (init == -1)                    \
    {                                  \
      init = millis();                 \
    }                                  \
    if (millis() - init > MS)          \
    {                                  \
      X;                               \
      init = millis();                 \
    }                                  \
  } while (0)

// Pin definitions
#define LED_PIN 37

// Default parameter values
#define DEFAULT_ENCODER_OFFSET 187.5f
#define DEFAULT_WHEELBASE 0.185f
#define DEFAULT_TRACK_WIDTH 0.15f

// Control constants
#define COMMAND_TIMEOUT_MS 200
#define MIN_VELOCITY_THRESHOLD 0.01f
#define MAX_STEERING_ANGLE_DEG 30.0f
#define WHEEL_RADIUS_M 0.0325f
#define MAX_RPM 300.0f
#define DEBUG_ARRAY_RIGHT_MOTOR_RPM_IDX 14
#define DEBUG_ARRAY_LEFT_MOTOR_RPM_IDX 15

// ROS Publishers and Subscribers
rcl_publisher_t car_state_publisher;
rcl_publisher_t debug_publisher;
rcl_subscription_t twist_subscriber;
rcl_subscription_t car_config_subscriber;

// ROS Messages
car_state_msg__msg__CarState car_state_msg;
std_msgs__msg__Float32MultiArray debug_msg;
geometry_msgs__msg__Twist twist_msg;
car_config_msg__msg__CarConfig car_config_msg;

// ROS Infrastructure
rclc_executor_t executor;
rclc_support_t support;
rcl_allocator_t allocator;
rcl_node_t node;
rcl_timer_t control_timer;
rcl_timer_t debug_timer;
rcl_timer_t kinematics_timer;

// Global objects
Car car(CS_RIGHT, CS_LEFT, CS_STEER);
SensorManager sensor_manager;
USBCDC USBSerial;

// State management
unsigned long long time_offset = 0;
unsigned long prev_cmd_time = 0;

// Runtime parameters (updated from car_config message)
float max_steering_angle = MAX_STEERING_ANGLE_DEG;
float max_rpm = MAX_RPM;
float wheel_radius = WHEEL_RADIUS_M;

enum states
{
  WAITING_AGENT,
  AGENT_AVAILABLE,
  AGENT_CONNECTED,
  AGENT_DISCONNECTED
} state;

// Function declarations
void flashLED(int n_times);
void rclErrorLoop();
bool createEntities();
bool destroyEntities();
void moveBase();
void publishData();
void syncTime();
struct timespec getTime();
void controlCallback(rcl_timer_t *timer, int64_t last_call_time);
void debugCallback(rcl_timer_t *timer, int64_t last_call_time);
void kinematicsCallback(rcl_timer_t *timer, int64_t last_call_time);
void twistCallback(const void *msgin);
void carConfigCallback(const void *msgin);

// Data arrays for multi-array messages
float debug_data_array[20];

void setup()
{
  pinMode(LED_PIN, OUTPUT);

  SPI.begin();
  SPI.setFrequency(1000000);

  if (!sensor_manager.initialize())
  {
    flashLED(3);
  }

  car.begin();
  USB.begin();
  USBSerial.begin(921600);

  while (!USBSerial)
  {
    delay(10);
    flashLED(1);
  }

  delay(2000);
  flashLED(2);

  set_microros_serial_transports(USBSerial);
  flashLED(6);

  car_state_msg__msg__CarState__init(&car_state_msg);
  std_msgs__msg__Float32MultiArray__init(&debug_msg);
  geometry_msgs__msg__Twist__init(&twist_msg);
  car_config_msg__msg__CarConfig__init(&car_config_msg);

  debug_msg.data.data = debug_data_array;
  debug_msg.data.capacity = 20;
  debug_msg.data.size = 20;

  debug_msg.layout.dim.data = NULL;
  debug_msg.layout.dim.size = 0;
  debug_msg.layout.dim.capacity = 0;
  debug_msg.layout.data_offset = 0;
}

void loop()
{
  static bool loop_started = false;
  if (!loop_started)
  {
    flashLED(7);
    loop_started = true;
  }

  switch (state)
  {
  case WAITING_AGENT:
    digitalWrite(LED_PIN, LOW);
    static bool waiting_announced = false;
    if (!waiting_announced)
    {
      flashLED(8);
      waiting_announced = true;
    }
    EXECUTE_EVERY_N_MS(500, state = (RMW_RET_OK == rmw_uros_ping_agent(100, 1)) ? AGENT_AVAILABLE : WAITING_AGENT;);
    break;
  case AGENT_AVAILABLE:
    digitalWrite(LED_PIN, LOW);
    state = (true == createEntities()) ? AGENT_CONNECTED : WAITING_AGENT;
    if (state == WAITING_AGENT)
    {
      flashLED(4);
      destroyEntities();
    }
    break;
  case AGENT_CONNECTED:
    digitalWrite(LED_PIN, HIGH);
    static bool connection_announced = false;
    if (!connection_announced)
    {
      flashLED(3);
      connection_announced = true;
    }
    EXECUTE_EVERY_N_MS(200, state = (RMW_RET_OK == rmw_uros_ping_agent(100, 1)) ? AGENT_CONNECTED : AGENT_DISCONNECTED;);
    if (state == AGENT_CONNECTED)
    {
      rclc_executor_spin_some(&executor, RCL_MS_TO_NS(10));
    }
    break;
  case AGENT_DISCONNECTED:
    digitalWrite(LED_PIN, LOW);
    flashLED(5);
    destroyEntities();
    state = WAITING_AGENT;
    break;
  default:
    digitalWrite(LED_PIN, LOW);
    break;
  }

  car.updateControlLoops();
}

void controlCallback(rcl_timer_t *timer, int64_t last_call_time)
{
  RCLC_UNUSED(last_call_time);
  if (timer != NULL)
  {
    moveBase();
    sensor_manager.update();
  }
}

void debugCallback(rcl_timer_t *timer, int64_t last_call_time)
{
  RCLC_UNUSED(last_call_time);
  if (timer != NULL)
  {
    SensorData sensor_data = sensor_manager.getLatestData();

    debug_data_array[0] = 1.0f;
    debug_data_array[1] = (float)millis();
    debug_data_array[2] = sensor_data.accel_x;
    debug_data_array[3] = sensor_data.accel_y;
    debug_data_array[4] = sensor_data.accel_z;
    debug_data_array[5] = sensor_data.gyro_x;
    debug_data_array[6] = sensor_data.gyro_y;
    debug_data_array[7] = sensor_data.gyro_z;
    debug_data_array[8] = car.speed;
    debug_data_array[9] = car.steeringAngle;
    debug_data_array[10] = (float)state;
    debug_data_array[11] = (float)ESP.getFreeHeap();
    debug_data_array[12] = (float)ESP.getHeapSize();
    debug_data_array[13] = (float)twist_msg.linear.x;
    debug_data_array[14] = (float)twist_msg.angular.z;
    debug_data_array[15] = (float)(millis() - prev_cmd_time);
    debug_data_array[16] = (float)time_offset;
    debug_data_array[17] = (float)car.getRightMotorRPM();
    debug_data_array[18] = (float)car.getLeftMotorRPM();
    debug_data_array[19] = (float)ESP.getCpuFreqMHz();

    debug_msg.data.data = debug_data_array;
    debug_msg.data.size = 20;
    debug_msg.data.capacity = 20;

    RCSOFTCHECK(rcl_publish(&debug_publisher, &debug_msg, NULL));
  }
}

void kinematicsCallback(rcl_timer_t *timer, int64_t last_call_time)
{
  RCLC_UNUSED(last_call_time);
  if (timer != NULL)
  {
    publishData();
  }
}

void twistCallback(const void *msgin)
{
  const geometry_msgs__msg__Twist *twist = (const geometry_msgs__msg__Twist *)msgin;

  if (twist == NULL)
  {
    return;
  }

  twist_msg.linear.x = twist->linear.x;
  twist_msg.linear.y = twist->linear.y;
  twist_msg.linear.z = twist->linear.z;
  twist_msg.angular.x = twist->angular.x;
  twist_msg.angular.y = twist->angular.y;
  twist_msg.angular.z = twist->angular.z;

  prev_cmd_time = millis();
}

bool createEntities()
{
  allocator = rcl_get_default_allocator();

  RCCHECK(rclc_support_init(&support, 0, NULL, &allocator));
  RCCHECK(rclc_node_init_default(&node, "car_controller", "", &support));

  RCCHECK(rclc_publisher_init_best_effort(
      &car_state_publisher,
      &node,
      ROSIDL_GET_MSG_TYPE_SUPPORT(car_state_msg, msg, CarState),
      "car/car_state"));

  RCCHECK(rclc_publisher_init_best_effort(
      &debug_publisher,
      &node,
      ROSIDL_GET_MSG_TYPE_SUPPORT(std_msgs, msg, Float32MultiArray),
      "car/debug_data"));

  RCCHECK(rclc_subscription_init_best_effort(
      &twist_subscriber,
      &node,
      ROSIDL_GET_MSG_TYPE_SUPPORT(geometry_msgs, msg, Twist),
      "cmd_vel_filtered"));

  RCCHECK(rclc_subscription_init_best_effort(
      &car_config_subscriber,
      &node,
      ROSIDL_GET_MSG_TYPE_SUPPORT(car_config_msg, msg, CarConfig),
      "car/config"));

  car.steeringMotor.setEncoderOffset(DEFAULT_ENCODER_OFFSET);
  car.wheelbase = DEFAULT_WHEELBASE;
  car.trackWidth = DEFAULT_TRACK_WIDTH;

  const unsigned int control_timeout = 20;
  RCCHECK(rclc_timer_init_default(
      &control_timer,
      &support,
      RCL_MS_TO_NS(control_timeout),
      controlCallback));

  const unsigned int debug_timeout = 500;
  RCCHECK(rclc_timer_init_default(
      &debug_timer,
      &support,
      RCL_MS_TO_NS(debug_timeout),
      debugCallback));

  const unsigned int kinematics_timeout = 50;
  RCCHECK(rclc_timer_init_default(
      &kinematics_timer,
      &support,
      RCL_MS_TO_NS(kinematics_timeout),
      kinematicsCallback));

  executor = rclc_executor_get_zero_initialized_executor();
  // 2 subscriptions + 3 timers = 5 handles
  RCCHECK(rclc_executor_init(&executor, &support.context, 5, &allocator));

  RCCHECK(rclc_executor_add_subscription(
      &executor,
      &twist_subscriber,
      &twist_msg,
      &twistCallback,
      ON_NEW_DATA));
  RCCHECK(rclc_executor_add_subscription(
      &executor,
      &car_config_subscriber,
      &car_config_msg,
      &carConfigCallback,
      ON_NEW_DATA));
  RCCHECK(rclc_executor_add_timer(&executor, &control_timer));
  RCCHECK(rclc_executor_add_timer(&executor, &debug_timer));
  RCCHECK(rclc_executor_add_timer(&executor, &kinematics_timer));

  syncTime();

  return true;
}

bool destroyEntities()
{
  rmw_context_t *rmw_context = rcl_context_get_rmw_context(&support.context);
  (void)rmw_uros_set_context_entity_destroy_session_timeout(rmw_context, 0);

  rcl_ret_t rc = rcl_publisher_fini(&car_state_publisher, &node);
  rc += rcl_publisher_fini(&debug_publisher, &node);
  rc += rcl_subscription_fini(&twist_subscriber, &node);
  rc += rcl_subscription_fini(&car_config_subscriber, &node);
  rc += rcl_node_fini(&node);
  rc += rcl_timer_fini(&control_timer);
  rc += rcl_timer_fini(&debug_timer);
  rc += rcl_timer_fini(&kinematics_timer);
  rc += rclc_executor_fini(&executor);
  rc += rclc_support_fini(&support);

  return rc == RCL_RET_OK;
}

void moveBase()
{
  if (((millis() - prev_cmd_time) >= COMMAND_TIMEOUT_MS))
  {
    twist_msg.linear.x = 0.0;
    twist_msg.linear.y = 0.0;
    twist_msg.angular.z = 0.0;
  }

  float linear_x = twist_msg.linear.x;
  float angular_z = twist_msg.angular.z;
  float steering_angle = 0.0f;

  if (fabs(linear_x) > MIN_VELOCITY_THRESHOLD && fabs(angular_z) > MIN_VELOCITY_THRESHOLD)
  {
    float turning_radius = linear_x / angular_z;
    steering_angle = atanf(car.wheelbase / turning_radius) * (180.0f / M_PI);
  }

  if (steering_angle > max_steering_angle)
    steering_angle = max_steering_angle;
  if (steering_angle < -max_steering_angle)
    steering_angle = -max_steering_angle;

  float speed_rpm = (linear_x / wheel_radius) * (60.0f / (2.0f * M_PI));

  if (speed_rpm > max_rpm)
    speed_rpm = max_rpm;
  if (speed_rpm < -max_rpm)
    speed_rpm = -max_rpm;

  debug_data_array[DEBUG_ARRAY_RIGHT_MOTOR_RPM_IDX] = car.getRightMotorRPM();
  debug_data_array[DEBUG_ARRAY_LEFT_MOTOR_RPM_IDX] = car.getLeftMotorRPM();

  car.setSteeringAngle(steering_angle);
  car.setSpeed(speed_rpm, car.wheelbase, car.trackWidth);
  car.updateControlLoops();
}

void publishData()
{
  SensorData sensor_data = sensor_manager.getLatestData();

  car_state_msg.accel_x = sensor_data.accel_x;
  car_state_msg.accel_y = sensor_data.accel_y;
  car_state_msg.accel_z = sensor_data.accel_z;
  car_state_msg.gyro_x = sensor_data.gyro_x;
  car_state_msg.gyro_y = sensor_data.gyro_y;
  car_state_msg.gyro_z = sensor_data.gyro_z;
  car_state_msg.speed = car.speed;
  car_state_msg.steering_angle = car.getActualSteeringAngle();
  car_state_msg.right_motor_rpm = car.getRightMotorRPM();
  car_state_msg.left_motor_rpm = car.getLeftMotorRPM();

  struct timespec time_stamp = getTime();
  car_state_msg.header.stamp.sec = time_stamp.tv_sec;
  car_state_msg.header.stamp.nanosec = time_stamp.tv_nsec;
  car_state_msg.header.frame_id.data = "base_link";
  car_state_msg.header.frame_id.size = 9;
  car_state_msg.header.frame_id.capacity = 9;

  RCSOFTCHECK(rcl_publish(&car_state_publisher, &car_state_msg, NULL));
}

void carConfigCallback(const void *msgin)
{
  const car_config_msg__msg__CarConfig *config = (const car_config_msg__msg__CarConfig *)msgin;

  if (config == NULL)
  {
    return;
  }

  // Update car configuration from received message
  car.wheelbase = (float)config->wheelbase;
  car.trackWidth = (float)config->track_width;
  wheel_radius = (float)config->wheel_radius;
  car.steeringMotor.setEncoderOffset((float)config->encoder_offset);
  max_steering_angle = (float)config->max_steering_angle;
  max_rpm = (float)config->max_rpm;
}

void syncTime()
{
  unsigned long now = millis();
  RCCHECK(rmw_uros_sync_session(10));
  unsigned long long ros_time_ms = rmw_uros_epoch_millis();
  time_offset = ros_time_ms - now;
}

struct timespec getTime()
{
  struct timespec tp = {0};
  unsigned long long now = millis() + time_offset;
  tp.tv_sec = now / 1000;
  tp.tv_nsec = (now % 1000) * 1000000;
  return tp;
}

void rclErrorLoop()
{
  while (true)
  {
    flashLED(2);
  }
}

void flashLED(int n_times)
{
  for (int i = 0; i < n_times; i++)
  {
    digitalWrite(LED_PIN, HIGH);
    delay(150);
    digitalWrite(LED_PIN, LOW);
    delay(150);
  }
  delay(1000);
}

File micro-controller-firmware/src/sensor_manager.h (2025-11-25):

#ifndef SENSOR_MANAGER_H
#define SENSOR_MANAGER_H

#include <Arduino.h>
#include <SparkFunLSM6DSO.h>

#define CS_IMU 14

struct SensorData {
    float gyro_x = 0.0f;
    float gyro_y = 0.0f;
    float gyro_z = 0.0f;
    float accel_x = 0.0f;
    float accel_y = 0.0f;
    float accel_z = 0.0f;
    float temperature = 0.0f;
    float right_rpm = 0.0f;
    float left_rpm = 0.0f;
    uint32_t last_update_ms = 0;
    bool data_valid = false;
};

class SensorManager {
public:
    SensorManager();
    ~SensorManager();
    
    // Initialization
    bool initialize();
    void cleanup();
    
    // Data access
    SensorData getLatestData();
    bool isDataValid() const;
    
    // Update methods
    void update();
    
    // IMU specific methods
    bool isIMUReady() const;
    float getTemperature() const;
    
    // Single-threaded operation
    void startSensorTask() {} // No-op for compatibility
    void stopSensorTask() {}  // No-op for compatibility
    
private:
    // IMU
    LSM6DSO imu_;
    bool imu_initialized_;
    int cs_pin_;
    
    // Sensor data
    SensorData sensor_data_;
    
    // Internal methods
    void readIMUData();
    void updateSensorData();
};

#endif // SENSOR_MANAGER_H

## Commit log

2025-09-03 Design files and Assembly Manual (#1)
    * Current V1 Design Files
    Work in progress
    * Design updates
    STEP and STL Files with updated steering
    * Fixing Folders Pt. 1
    * Fixed folder issue
    * Updates to battery holder
    * Small updates and Guidance Doc
    Updates to Rear shrouds.
    Added Lidar clip.
    Added Guidance for 3d Printing, Electrical, and Assembly
    * Camera Mount
    Added Camera Mount to STEP and STL.
    * Added rear wheel spacing tool
    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
    [12t Pinion_v3.step, 12t Pinion_v3.stl, 55t gear_v1.step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]
2025-11-25 moving code from "refactor/imu-and-encoder-publishing" and adding additional documentation
